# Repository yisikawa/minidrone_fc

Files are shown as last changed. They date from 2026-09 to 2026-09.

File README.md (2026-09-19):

# minidrone_fc — ミニドローン制御基板 KiCadプロジェクト

1S LiPo / 8520コアレスモーター×4 / 目標58g・上限70g

回路図は生成済みです。手で描く必要はありません。

---

## 1. 使い方

1. このフォルダごと `D:\KicadProjects\` などに置く（`D:\Kicad`
   の中には置かないでください。KiCad更新時に消える可能性があります）
2. `minidrone_fc.kicad_pro` をダブルクリック
3. 回路図（`.kicad_sch`）を開く

**KiCad 10で開くとファイル形式の変換確認が出ます。**
このプロジェクトはKiCad 7形式で生成されているためです。
「はい」で変換してください。以後は10形式で保存されます。

---

## 2. 最初にやること: XIAOのフットプリント設定

**U1のフットプリントは意図的に空欄にしてあります。**
XIAOはKiCad公式ライブラリに含まれず、環境によってライブラリ名が
変わるため、こちらで決め打ちできませんでした。

手順:

1. https://github.com/Seeed-Studio/OPL_Kicad_Library をZIPで取得
2. 展開し、`Seeed Studio XIAO Series Library/` 内の `.kicad_sym` を
   設定 → シンボルライブラリを管理 から追加
3. フットプリントは `.pretty` フォルダに入っていないと認識されません。
   単体の `.kicad_mod` ファイルの場合は `Seeed_XIAO.pretty` という
   フォルダを作って中に移動してから、
   設定 → フットプリントライブラリを管理 で追加
4. 回路図でU1を選択 → E キー → Footprintフィールドに
   `Seeed_XIAO:XIAO-ESP32C3-SMD` のような実際の名前を入力

U1のシンボル自体はこのプロジェクト内の `minidrone.kicad_sym` に
同梱してあるので、シンボルライブラリの導入は必須ではありません。
必要なのはフットプリントだけです。

---

## 3. 検証済みの内容

このプロジェクトは生成後、KiCadのエンジン（kicad-cli）で
以下を実機検証しています。

| 検証項目 | 結果 |
|---|---|
| 回路図ファイルの読み込み | 成功 |
| 基板ファイルの読み込み | 成功 |
| 部品点数 | 37点（設計意図と一致） |
| フットプリント割り当て | 全点一致（U1除く） |
| ネット数 | 22ネット |
| 接続点の総数 | 96点 |
| ネットリスト照合 | **全ネット完全一致** |
| 意図しない結線 | なし |
| 未結線ピン | 16点（すべてno_connect指定済み） |

つまり、書き出したネットリストが設計表と1本残らず一致することを
確認済みです。回路図の入力ミスはありません。

---

## 4. 設計資料からの変更点

基板化の過程で判明した誤りを訂正しています。

| 項目 | 変更前 | 変更後 | 理由 |
|---|---|---|---|
| 極性コンデンサ | `Device:CP` | `Device:C_Polarized` | CPはKiCad 5時代の名前。現行ライブラリに存在しない |
| フライバックダイオード | SS14 | **SS24** | SS14は1A定格。モーター電流1.62Aに対し余裕が乏しい。SS24は2A定格で、フットプリントは同じD_SMAなのでレイアウト変更不要 |
| C3〜C6の接続先 | Qのドレイン–ソース間 | **VBAT–GND間** | 高周波電流ループを閉じるのは電源側。低側スイッチではこちらが標準 |
| PTCヒューズ・電源SW | あり | **削除** | 6.5Aでは直列抵抗による電圧降下が推力損失に直結する |

---

## 5. ピン割り当て（ESP32-C3の制約を反映済み）

| XIAOピン | GPIO | ネット | 備考 |
|---|---|---|---|
| D0 | GPIO2 | 未使用 | ストラッピングピン。使用不可 |
| D1 | GPIO3 | BATT_SENSE | ADC1。Wi-Fi動作中も使える |
| D2 | GPIO4 | GATE_FL | |
| D3 | GPIO5 | GATE_FR | |
| D4 | GPIO6 | SDA | |
| D5 | GPIO7 | SCL | |
| D6 | GPIO21 | GATE_RL | |
| D7 | GPIO20 | IMU_INT | MPU6050のデータレディ割り込み |
| D8 | GPIO8 | 未使用 | ストラッピングピン |
| D9 | GPIO9 | 未使用 | BOOTピン |
| D10 | GPIO10 | GATE_RR | |

**A0はD0と同一ピンです。** そしてGPIO2はストラッピングピンなので、
電圧センスはD1（GPIO3）に置いてあります。またESP32-C3のADC2は
Wi-Fi動作中に使えないため、ADC1に属するピンでなければなりません。

D7をIMU割り込みに使っているので、将来UART受信機を追加する場合は
再割り当てが必要です。

---

## 6. 次の手順（基板レイアウト）

1. Eeschemaで ツール → フットプリントを割り当て を開き、U1だけ設定
2. 検査 → エレクトリカルルールチェック(ERC) を実行
3. ツール → 基板エディタで基板を更新
4. 基板の外形（Edge.Cuts）を35×35mmで描く
5. 配置は以下の順序で。**この順序が重要です**
   - モーターパッド J2〜J5 を四隅に
   - Q1〜Q4 と D1〜D4 を対応するパッドの直近（5mm以内）に
   - C3〜C6 を各Qの直近に
   - U1を中央、USB-Cが基板端から出る向きに
   - U2を裏面中央、モーター電流経路を避けた位置に
6. デザインルール: 最小クリアランス0.2mm、最小トレース幅0.25mm、
   ビア0.6mm/ドリル0.3mm
7. VBATとGNDはトレースではなく**ベタ（カッパープアー）**で。
   6.5Aには1oz銅で約4.0mm幅のトレースが必要で、35mm角では引けません
8. M_FL〜M_RRは1.0mm幅以上

### レイアウトで最も重要な点

**フライバックループの面積を最小化してください。**
モーターOFFの瞬間、逆起電力が モーター → D → VBAT → モーター を
流れます。このループが囲む面積がそのままノイズの放射源になり、
MPU6050の読み値を汚します。D1〜D4は必ずモーターパッドの真横に、
ビアを挟まずに配置してください。

---

## 7. 未検証事項

- **XIAOフットプリントの実寸**: Seeedのライブラリで裏面パッドや
  サーマルパッドの欠落が報告されています。実物を基板に当てて
  確認してください
- **MPU6050のQFN-24実装**: 手はんだは難度が高めです。困難なら
  GY-521完成基板（+1〜2g）に戻す判断もあり得ます
- **フレーム側の穴位置**: モーターパッドの座標はフレーム設計と
  同時に決める必要があります。基板レイアウトの前にフレーム寸法を
  確定させてください
- **ガーバー出力は未実施**: 発注前にDRCとガーバービューアでの
  目視確認を必ず行ってください

---

## 8. rev2 での修正（ERC結果を反映）

初版に対してERCを実行した結果、エラー3件・警告137件を修正しました。

| 症状 | 件数 | 原因 | 対応 |
|---|---|---|---|
| `power_pin_not_driven` | 3（エラー） | XIAOの3V3ピンを`power_in`と定義していた。実際はレギュレータ**出力**。またGND/VMCUに駆動源が明示されていなかった | 3V3を`power_out`に修正。VBAT/GND/VMCUにPWR_FLAGを追加 |
| `endpoint_off_grid` | 133（警告） | 部品座標が1.27mm（50mil）グリッドに乗っていなかった | 全部品を1.27mmグリッドにスナップ |
| `lib_symbol_mismatch` | 4（警告） | AO3400Aは本来`extends BSS138`の派生シンボル。展開して埋め込んだためライブラリ本体と差異が出る | 下記参照 |

### lib_symbol_mismatch について

これは**動作に影響しない表示上の警告**です。KiCad 7の回路図フォーマットが
`extends` を受け付けないため、生成側で展開する必要がありました。

解消したい場合は、KiCad 10で
**ツール → シンボルをライブラリから更新** を実行してください。
埋め込みコピーがKiCad 10のライブラリ版に置き換わり、警告が消えます。
接続には影響しません。

### 修正後の検証結果

- 回路図・基板ファイルの読み込み: 成功
- ネットリスト照合: **全22ネット・96接続点が完全一致**
- ワイヤ端点198点・ラベル99点・no_connect16点: **すべてグリッド上（off-grid 0）**
- BOM部品数: 37点（PWR_FLAG 3点はBOM除外）

---

## 9. rev2.1 での変更（2026-09-19）: 昇降圧DC-DC追加 + 4層化

### 9.1 なぜ必要だったか — 電源の設計欠陥

改訂前の電源経路は次のとおりでした。

```
VBAT (3.0-4.2V) --[D5 SS24, 約0.4V drop]--> VMCU --> U1(XIAO) pin14 "5V"
                        XIAO内蔵LDO --> +3V3 --> U2 GY-521, U3 BMP280
```

**この基板には昇圧素子が1つもありません。** そのため電池電圧が
「3.3V + LDOドロップアウト」を下回れば、3V3 レールは必ず追従して下がります。

8520コアレスモーター4個で 6.5A を引くと電池は 3.7V→3.4V 程度に沈み、
そこから D5 の 0.4V を引いて VMCU ≈ 3.0V、さらに XIAO 内蔵 LDO の
ドロップアウトを引くと **3V3 は 2.8〜2.95V**。
ESP32-C3 の動作下限 3.0V を公称電圧ですら下回っており、
**スロットルを上げた瞬間に MCU がリセットする**状態でした。

D5 が 0.4V を捨てていたのが最大の要因です。

### 9.2 対策 — TPS63002 昇降圧DC-DC の挿入

```
VBAT --> U4 TPS63002 (昇降圧, 5V固定) --> [D5 SS24] --> VMCU --> XIAO 5Vピン
             |                                              XIAO内蔵LDO --> +3V3（変更なし）
             +-- L1 2.2uH, C10 10uF(in), C11 22uF(out), C12 0.1uF(VINA)
```

- 電池が 3.0V まで落ちても出力5V固定。D5 で 0.4V 落ちても **4.6V** が XIAO に入る。
  内蔵LDO が 3.3V を作るのに必要なのは 3.5V 程度なので**余裕1V以上**
- 3.3V を XIAO の 3V3 ピンに逆流注入せず、XIAO が本来想定する "5V" ピンから
  入れているので、内蔵LDO と競合しない
- **+3V3 ネット（GY-521・BMP280）は一切変更していません**
- D5 は流用。向きも不変で、上流が VBAT から V5V に変わっただけ
- 効率は昇圧90%×LDO66%＝約60%だが、MCU消費0.33Wに対しモーターが24Wなので
  損失増は全体の0.75%

### 9.3 4層化

| 層 | 内容 |
|---|---|
| L1 F.Cu | 信号 + U1/U2 + 既存の VBAT ベタ4枚（そのまま残置） |
| **L2 In1.Cu** | **ベタGND 全面 2949mm²** |
| **L3 In2.Cu** | **VBAT プレーン 全面 2811mm²** |
| L4 B.Cu | 信号 + SMD部品 + GNDベタ |

改訂前は 6.5A を 0.6mm トレースで流していました。内層プレーン全面に変更。
GND スティッチングビアを 133本、衝突判定付きで自動配置しています。

### 9.4 U4 のローカルクリアランス 0.1mm について

VSON-10 は 0.5mm ピッチ・パッド幅 0.28mm でパッド間が 0.22mm しかなく、
VBAT が属する Power ネットクラスの 0.25mm 要求を物理的に満たせません。
Power の 0.25mm はモーター大電流の配線・ベタ向けポリシーであり、
ファインピッチ IC のピン間に適用する意図ではないため、
U4 のフットプリントにローカル上書きを設定しています。
JLCPCB の製造限界は 0.1mm なので 0.22mm は十分製造可能です。

### 9.5 検証結果

| 項目 | 改訂前 | 改訂後 |
|---|---|---|
| DRC エラー | 0 | **0** |
| DRC 警告 | 32 | 37（増分5はすべてシルク重なり） |
| 未配線アイテム | 4 | **1**（改善） |
| schematic_parity | 0 | **0**（回路図と基板が完全一致） |
| ERC | warning 5 / error 0 | warning 5 / error 0（同一） |
| 既存部品のパッド-ネット変更 | — | **D5 pad2 の VBAT→V5V のみ** |

検証は `kicad-cli pcb drc` / `kicad-cli sch erc` で実施しています。
**KiCad MCP の `run_drc` は未接続アイテムを検査しないため、
発注前の最終確認は必ず `kicad-cli` か GUI の DRC で行ってください。**

### 9.6 まだ残っている課題

- **未配線1件**: GND ベタの孤立島が1つ残っています（改訂前は4件）。
  電気的な害はありませんが、気になる場合は GUI で該当箇所を確認してください
- **シルク警告 29+3件**: 新規部品 C10/C11/C12 のリファレンス文字が
  隣接銅箔に重なります。この一角は部品とビアで埋まっており逃がす余地が
  ありませんでした。JLCPCB はパッド上のシルクを自動クリップします
- **Gerber / BOM / 実装座標は再出力していません。** 4層基板として
  出力し直す必要があります
- **実機でのブラウンアウト解消は未検証です**

### 9.7 改訂前の状態に戻すには

改訂前 (rev2) の状態は最初のコミットにそのまま記録してあります。
タグ `rev2` / `rev2.1` から参照できます。

```
git show rev2 --stat      改訂前の内容
git diff rev2 rev2.1      今回の改訂差分
```

git 導入前に使っていた手動チェックポイント (`*.before-gy521`, `*.before-4layer` など)
とローカルのフルバックアップは、履歴で代替できるため追跡対象外にしています
(`.gitignore` 参照)。

詳細な作業記録は `docs/superpowers/plans/2026-09-19-buckboost-and-4layer.md`。

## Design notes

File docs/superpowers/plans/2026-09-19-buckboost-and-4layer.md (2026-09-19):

# minidrone_fc rev2: 昇降圧DC-DC追加 + 4層化 実装計画

> **For agentic workers:** REQUIRED SUB-SKILL: superpowers:executing-plans または
> superpowers:subagent-driven-development で1タスクずつ実施すること。

**Goal:** 既存 rev2 基板のブラウンアウト欠陥を TPS63002 昇降圧DC-DC で解消し、
基板を2層から4層に変更して 6.5A の VBAT を内層プレーンで流せるようにする。

**Architecture:** 既存回路には手を入れず、VBAT と XIAO の "5V" ピンの間に
TPS63002（昇降圧・5V固定出力）を挿入する。既存の D5（SS24）は VBAT→VMCU の
直列位置から TPS63002出力→VMCU に移すだけで流用する。+3V3 ネット
（GY-521・BMP280）は XIAO 内蔵 LDO から供給されたまま一切変更しない。

**Tech Stack:** KiCad 10.0 / kicad MCP (swig backend)

**Spec:** このファイルの「背景」節に内包（既存プロジェクトの改修のため独立specなし）

## 背景: なぜ必要か

現状の電源経路:

```
VBAT (3.0-4.2V) --[D5 SS24, 約0.4V drop]--> VMCU --> U1(XIAO) pin14 "5V"
                                              +-- C2 100uF
                        XIAO内蔵LDO --> +3V3 (pin12) --> U2 GY-521, U3 BMP280
```

8520コアレスモーター4個で 6.5A を引くと電池は 3.7V→3.4V 程度に沈む。
そこから D5 の 0.4V を引いて VMCU ≈ 3.0V、さらに XIAO 内蔵 LDO の
ドロップアウトを引くと 3V3 レールは **2.8〜2.95V**。
ESP32-C3 の動作下限 3.0V を公称電圧ですら下回っており、
スロットルを上げた瞬間に MCU がリセットする。

この基板には昇圧素子が一切ないため、電池電圧が
「3.3V + LDOドロップアウト」を下回れば 3V3 は必ず追従して下がる。
LDO や配線の改善では原理的に解決できない。

## Global Constraints

- **既存の回路図ネットのうち、+3V3 / GND / GATE_* / G_* / M_* / SCL / SDA /
  BATT_SENSE は変更しないこと。** 変更してよいのは VBAT・VMCU の接続と
  新規追加分のみ。
- **git commit は行わない**（ユーザー指示）。チェックポイントは既存プロジェクトの
  慣習に従い `<file>.before-<変更名>` のファイルコピーで残す。
- 設計ルール: 最小クリアランス 0.2mm / 最小トレース幅 0.25mm / ビア 0.6mm・ドリル 0.3mm
- 基板外形は現状の 50 x 64mm を変更しない。取付穴 M2.2 x4（44x44mm ピッチ）も変更しない。
- 新規部品は KiCad 標準ライブラリのシンボル・フットプリントのみ使用する。

## 部品追加リスト

| Ref | Value | Symbol | Footprint | 接続 |
|---|---|---|---|---|
| U4 | TPS63002 | `Regulator_Switching:TPS63002` | `Package_SON:VSON-10-1EP_3x3mm_P0.5mm_EP1.65x2.4mm_ThermalVias` | 下記 |
| L1 | 2.2uH | `Device:L` | `Inductor_SMD:L_APV_ANR3015` | U4/L1(4) - U4/L2(2) |
| C10 | 10u | `Device:C` | `Capacitor_SMD:C_0805_2012Metric` | VBAT - GND（U4入力） |
| C11 | 22u | `Device:C` | `Capacitor_SMD:C_0805_2012Metric` | V5V - GND（U4出力） |
| C12 | 0.1u | `Device:C` | `Capacitor_SMD:C_0603_1608Metric` | VINA - GND |

TPS63002 のピン接続（データシート SLVS520C 実測確認済み）:

| ピン | 名称 | 接続 | 根拠 |
|---|---|---|---|
| 1 | VOUT | V5V | 出力 |
| 2 | L2 | L1 の片側 | インダクタ |
| 3 | PGND | GND | パワーグランド |
| 4 | L1 | L1 のもう片側 | インダクタ |
| 5 | VIN | VBAT | パワー段電源 |
| 6 | EN | VBAT | "1 enabled" → 常時イネーブル |
| 7 | PS/SYNC | VBAT | "1 disabled(power-save)" → 強制PWM。Wi-Fiバースト負荷の過渡応答重視 |
| 8 | VINA | VBAT（C12 でデカップリング） | 制御段電源 |
| 9 | GND | GND | ロジックグランド |
| 10 | FB | V5V | **固定出力版は FB を VOUT に接続**（データシート明記） |
| 11 | EPAD | GND | 露出パッドは PGND に接続 |

## ネット変更

| ネット | 変更前 | 変更後 |
|---|---|---|
| VBAT | ... , D5/2 | ... , D5/2 を削除。U4/5, U4/6, U4/7, U4/8, C10/1 を追加 |
| **V5V**（新規） | — | U4/1, U4/10, C11/1, D5/2 |
| VMCU | D5/1, C2/1, U1/14 | 変更なし |
| GND | ... | U4/3, U4/9, U4/11, C10/2, C11/2, C12/2 を追加 |

D5 の向きは変えない（pin2=カソード側が電源上流、pin1=アノード側が VMCU）。
上流が VBAT から V5V に変わるだけ。

---

### Task 1: 回路図に TPS63002 ブロックを追加し ERC を通す

**Files:**
- Modify: `minidrone_fc.kicad_sch`
- Checkpoint: `minidrone_fc.kicad_sch.before-buckboost`

- [x] **Step 1: チェックポイントを作成**

```bash
cp minidrone_fc.kicad_sch minidrone_fc.kicad_sch.before-buckboost
```

- [x] **Step 2: 変更前のネットリストを記録**

`list_schematic_nets` を実行し、19ネットであること、
VBAT が 17ピン、VMCU が 4ピンであることを記録する。

- [x] **Step 3: U4 / L1 / C10 / C11 / C12 を配置**

`batch_add_components` で上記「部品追加リスト」のシンボルを、
回路図の空き領域（既存部品と重ならない座標）に配置する。

- [x] **Step 4: 結線**

`batch_connect` で「ネット変更」表のとおり接続する。
D5/2 を VBAT から切り離して V5V に繋ぎ替えるのを忘れないこと。

**落とし穴（2026-09-19 に実際に踏んだ）:** この回路図はピンから短いスタブ配線を
伸ばし、その**反対端**にラベルを置く方式で描かれている。`batch_connect` の
`replace=true` はピン位置のラベルしか削除しないため、スタブ反対端の既存 `VBAT`
ラベルが残り、同じ配線上に `VBAT` と `V5V` が同居して**両ネットが短絡**した。

正しい手順:
1. `batch_connect` で V5V ラベルを置く
2. `delete_schematic_net_label` で **(90.17, 49.53) の `VBAT` ラベルを削除**する
3. V5V ラベルもスタブ反対端 (90.17, 49.53) に置き直し、既存の作図スタイルに揃える
   （ピン位置に置いたままだと「未接続の配線終端」警告が出る）
4. `list_schematic_nets` で V5V が **4ピンちょうど**であることを必ず確認する。
   16ピン以上になっていたら VBAT と短絡している

- [x] **Step 5: ネットリストを検証**

`list_schematic_nets` を実行。期待値（2026-09-19 実測で確認済み）:
- ネット数 19 → **22**（V5V・SW_L1・SW_L2 の3本が増える）
- VBAT: 17 → **22ピン**（D5/2 が抜け、U4/5・U4/6・U4/7・U4/8・C10/1・C12/1 が入る）
- V5V: **4ピン**（D5/2, U4/1, U4/10, C11/1）
- SW_L1: **2ピン**（U4/4, L1/1）／ SW_L2: **2ピン**（U4/2, L1/2）
- VMCU: **4ピン**（変更なし）
- +3V3: **7ピン**（変更なし）
- GND: 25 → **31ピン**

注: `list_schematic_nets` のピン数ヘッダは PWR_FLAG を含むが一覧には
表示されない。VBAT はヘッダ17に対し一覧16件、GND はヘッダ25に対し一覧24件
という差がある。そのため**絶対値ではなく上記の増減で判定すること。**

- [x] **Step 6: ERC を実行**

`run_erc` を実行。期待値: **エラー0件**。
`power_pin_not_driven` が出た場合、V5V に PWR_FLAG を追加する
（既存プロジェクトが VBAT/GND/VMCU で同じ対処をしている）。

---

### Task 2: 基板を4層に変更する

**Files:**
- Modify: `minidrone_fc.kicad_pcb`
- Checkpoint: `minidrone_fc.kicad_pcb.before-4layer`

- [x] **Step 1: チェックポイントを作成**

```bash
cp minidrone_fc.kicad_pcb minidrone_fc.kicad_pcb.before-4layer
```

- [x] **Step 2: 層を追加**

`add_layer` で `In1.Cu` と `In2.Cu` を signal/power 層として追加し、
`get_layer_list` で F.Cu / In1.Cu / In2.Cu / B.Cu の4層になったことを確認する。

- [x] **Step 3: F.Cu の VBAT ベタは削除しない（方針変更）**

当初は F.Cu の VBAT ベタ4枚を削除する計画だったが、**削除しないことにした。**

理由:
1. **ゾーンを削除する専用 MCP ツールが存在しない**（`delete_graphic` は
   グラフィック用でゾーンには使えない）
2. 残しても VBAT の銅箔が増えるだけで害がない。F.Cu の配線余地は
   既に配線完了済みのため不要
3. 危険な操作を1つ減らせる

目的（L2 ベタGND・L3 VBAT プレーンの獲得）は追加のみで達成できる。

- [x] **Step 4: 内層ベタを追加**

`add_copper_pour` で以下を作成する。`outline` を省略すると基板外形が使われる。

- `In1.Cu` = **GND**、clearance 0.2
- `In2.Cu` = **VBAT**、clearance 0.2

- [x] **Step 5: ゾーンを再充填して検証**

**注意: `refill_zones` は swig バックエンドで segfault の既知リスクあり。**
実行直前に `cp minidrone_fc.kicad_pcb minidrone_fc.kicad_pcb.before-refill` で
チェックポイントを取ること。（2026-09-19 の実行では segfault は発生しなかった）

**既知の誤検知:** `refill_zones` が
「Auto-save refused: ... changed externally」と警告を返すことがあるが、
これは MCP 側の mtime 記録が自身の直前の書き込みで古くなったための誤検知で、
**実際にはディスクに書き込まれている**。ファイルサイズの増加と
`grep -c filled_polygon` で確認し、`reload_board` で MCP を再同期すること。

検証結果（2026-09-19 実測）: 全7ゾーン `isFilled: true`。
In1.Cu GND = 2956mm²、In2.Cu VBAT = 2949mm²（基板面積 3200mm² のほぼ全面）。

---

### Task 3: 新規部品を配置し配線する

**Files:**
- Modify: `minidrone_fc.kicad_pcb`
- Checkpoint: `minidrone_fc.kicad_pcb.before-dcdc-place`

- [x] **Step 1: チェックポイントを作成**

```bash
cp minidrone_fc.kicad_pcb minidrone_fc.kicad_pcb.before-dcdc-place
```

- [x] **Step 2: 回路図の変更を基板に反映**

`sync_schematic_to_board` を実行し、U4 / L1 / C10 / C11 / C12 が
基板に追加されたことを `get_component_list` で確認する。

- [x] **Step 3: U4 ブロックを配置**

B.Cu（他のSMD部品と同じ面）の空き領域に配置する。
現状 y=50〜64 の帯（J1 BATT・C1・C2 のあるエリア）に空きがあるため、
**C2（VMCU のバルク、座標 34,56）と J1（BATT、座標 8,54）の間**に U4 を置く。
これにより VBAT 入口（J1）→ U4 → C2/VMCU が最短で繋がる。

配置後 `check_placement_clearance` で既存部品と干渉しないことを確認する。

**レイアウト上の必須要件:**
- L1 は U4 の L1/L2 ピンの直近（3mm以内）に置く。スイッチングノードの
  ループ面積がそのままEMIになる
- C10（入力）は U4 の VIN/PGND ピンの直近に置く
- C11（出力）は U4 の VOUT/PGND ピンの直近に置く
- U4 の露出パッド直下にサーマルビアを配置し In1.Cu(GND) に落とす

- [x] **Step 4: 配線**

`route_pad_to_pad` で V5V / VBAT / GND / スイッチングノードを接続する。
V5V と VBAT は **0.5mm 幅以上**（MCU電流のみなので大電流は不要だが、
インピーダンスを下げる）。

- [x] **Step 5: ゾーン再充填**

`refill_zones` を実行する。

---

### Task 4: DRC を通し、警告を仕上げる

**Files:**
- Modify: `minidrone_fc.kicad_pcb`

- [x] **Step 1: DRC を実行**

`run_drc` を実行し、違反を種別ごとに記録する。

- [x] **Step 2: エラーをゼロにする**

`error` severity の違反をすべて解消する。
クリアランス違反は部品をずらすか配線を引き直す。

- [x] **Step 3: silk_over_copper 警告を減らす**

変更前は 26件あった。`move_footprint_text` でシルクを
銅箔・パッドから逃がす。JLCPCB はパッド上のシルクをクリップするため、
リファレンス指示子が読めなくなるのを防ぐ目的。

- [x] **Step 4: 最終検証**

以下をすべて満たすことを確認して完了とする。

- `run_erc`: エラー0件
- `run_drc`: **エラー0件**
- `query_zones`: 全ゾーン `isFilled: true`
- `get_layer_list`: F.Cu / In1.Cu / In2.Cu / B.Cu の4層
- `list_schematic_nets`: 20ネット、V5V が4ピン、+3V3 が7ピン

## 完了後に残る課題（この計画の対象外）

- Gerber / BOM / 実装座標の再出力（成果物範囲外）
- 4層化に伴う JLCPCB の製造コスト変更の確認
- 実機でのブラウンアウト解消の検証

---

## 実施結果（2026-09-19 完了）

### 最終検証値

| 項目 | 変更前 | 変更後 | 判定 |
|---|---|---|---|
| DRC 違反 | 32（すべて warning） | 37（すべて warning） | エラー0を維持。増分5はすべてシルク |
| DRC エラー | 0 | **0** | OK |
| 未配線アイテム | 4 | **1** | 改善 |
| schematic_parity | 0 | **0** | 回路図と基板が完全一致 |
| ERC | warning 5 / error 0 | warning 5 / error 0 | 変更前と同一 |
| 既存部品のパッド-ネット変更 | — | **D5 pad2 の VBAT→V5V のみ** | 意図どおり |

増分5件のシルク警告は silk_over_copper 26→29、silk_overlap 1→3。
新規部品 C10/C11/C12 のリファレンス文字が隣接銅箔に重なるもので、
この一角は J1・D5・C1・U4・L1 とスティッチングビアで埋まっており逃がす余地がない。
ベースラインに既に26件ある同種の警告であり、エラーではなく、
JLCPCB はパッド上のシルクを自動クリップするため許容とした。

### 実際に行った変更

1. 回路図に U4(TPS63002) / L1(2.2uH) / C10(10u) / C11(22u) / C12(0.1u) を追加
2. D5 の上流を VBAT から V5V に変更（D5 の向きは不変）
3. In1.Cu(GND) / In2.Cu(VBAT) の内層プレーンを追加し4層化
4. U4 にローカルクリアランス 0.1mm を設定（下記参照）
5. GND スティッチングビア 133本を自動配置（衝突判定付き）
6. GND ゾーンの島除去モードを ALWAYS に設定

### U4 のローカルクリアランス 0.1mm について

VSON-10 は 0.5mm ピッチ・パッド幅 0.28mm でパッド間が 0.22mm しかなく、
VBAT が属する Power ネットクラスの 0.25mm 要求を物理的に満たせない。
Power の 0.25mm はモーター大電流の配線・ベタ向けポリシーであり、
ファインピッチ IC のピン間に適用する意図のものではないため、
U4 のフットプリントにローカル上書きを設定した。
JLCPCB の製造限界は 0.1mm なので 0.22mm は十分製造可能。

### 作業中に検出・修正した不具合

| 不具合 | 原因 | 検出方法 |
|---|---|---|
| VBAT と V5V の短絡 | `batch_connect` の `replace` がスタブ反対端の既存ラベルを消さない | ネットリスト検証（V5V が 4→20ピン） |
| VBAT と V5V の短絡（基板側） | 既存 VBAT トレースが D5/2 を中継点に使用していた | DRC shorting_items |
| V5V が C11 の GND パッドを貫通 | C11 の V5V パッドが進入方向と逆側 | DRC shorting_items |
| **U1 pad7 に GATE_RL 重複、U2 pad8(GY-521 INT) に +3V3 直結** | `sync_schematic_to_board` が回路図にない割り当てを追加 | 変更前後のパッド-ネット差分 |

最後の1件は DRC でも ERC でも検出されない。
**`sync_schematic_to_board` の後は必ず変更前後のパッド-ネット差分を取ること。**

### ツール上の注意点（次回のために）

- **`mcp__kicad__run_drc` は未接続アイテムを検査しない。** エラー0でも配線が
  繋がっていない場合がある。`kicad-cli pcb drc` を正とすること
- **`mcp__kicad__refill_zones` は4層フルプレーンで30秒タイムアウトする。**
  KiCad 同梱の `pcbnew` Python（`D:\KiCad\10.0\bin\python.exe`）で
  `ZONE_FILLER(b).Fill(b.Zones())` を直接実行して回避した
- `refill_zones` / `sync_schematic_to_board` の後は MCP の mtime 記録が古くなり
  以降の書き込みが「Auto-save refused」で無視される。**必ず `reload_board` すること**
- pcbnew Python の落とし穴:
  - `b.Tracks()` / `b.Zones()` は**一度しかイテレートできない**。`list()` で取り置く
  - ゾーンは `b.GetArea(i)` で取ると正しい `ZONE` 型になる
  - `b.Remove()` を呼ぶと**以降の既存ラッパが無効化される**。
    読み取りを全部終えてから変更すること
  - `PCB_VIA.GetWidth()` は KiCad 10 で層引数が必須

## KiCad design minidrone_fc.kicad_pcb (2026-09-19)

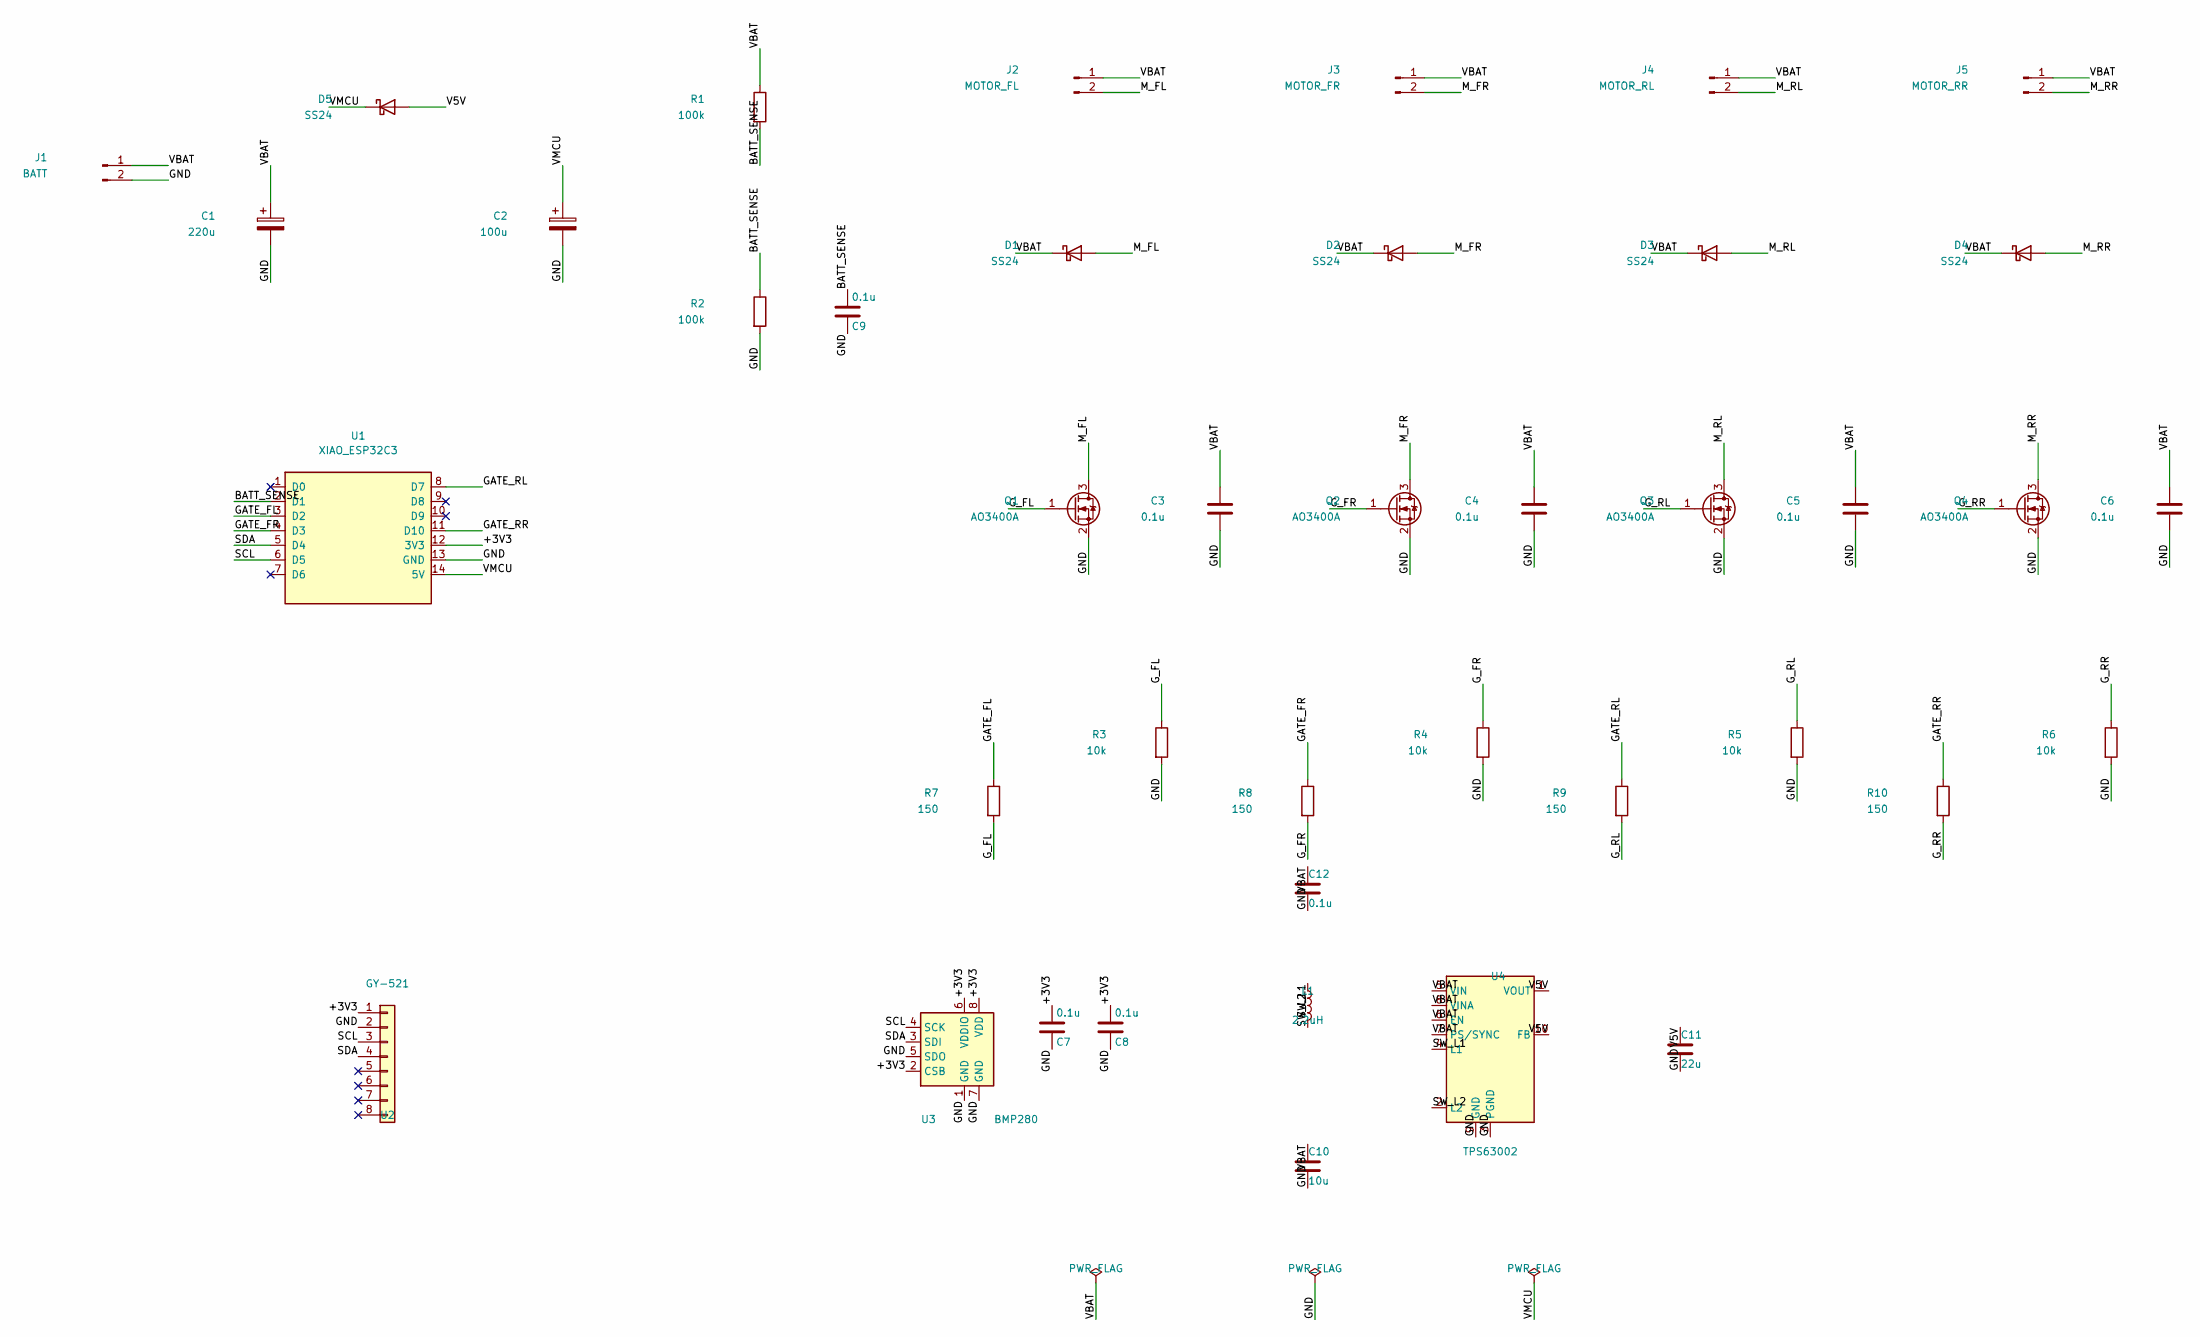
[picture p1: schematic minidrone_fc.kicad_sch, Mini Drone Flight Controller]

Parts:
C1: 220u; CP_Elec_6.3x5.3; Voltage 10V; MPN CS1A221M-CRE54; LCSC C116413
C2: 100u; CP_Elec_6.3x5.3; Voltage 16V; MPN CK1C101M-CRE54; LCSC C129250
C3, C4, C5, C6, C7, C8, C9: 0.1u; C_0603_1608Metric; MPN CC0603KRX7R9BB104; LCSC C14663
C10: 10u; C_0805_2012Metric
C11: 22u; C_0805_2012Metric
C12: 0.1u; C_0603_1608Metric
D1, D2, D3, D4, D5: SS24; D_SMA; MPN SS24; LCSC C115726
J1: BATT; JST_PH_S2B-PH-K_1x02_P2.00mm_Horizontal; MPN S2B-PH-K-S(LF)(SN); LCSC C173752
J2: MOTOR_FL; TestPoint_2Pads_Pitch2.54mm_Drill0.8mm
J3: MOTOR_FR; TestPoint_2Pads_Pitch2.54mm_Drill0.8mm
J4: MOTOR_RL; TestPoint_2Pads_Pitch2.54mm_Drill0.8mm
J5: MOTOR_RR; TestPoint_2Pads_Pitch2.54mm_Drill0.8mm
L1: 2.2uH; L_APV_ANR3015
Q1, Q2, Q3, Q4: AO3400A; SOT-23; MPN AO3400A; LCSC C20917
R1, R2: 100k; R_0603_1608Metric; MPN 0603WAF1003T5E; LCSC C25803
R3, R4, R5, R6: 10k; R_0603_1608Metric; MPN RK73H1JTTD1002F; LCSC C130232
R7, R8, R9, R10: 150; R_0603_1608Metric; MPN 0603WAF1500T5E; LCSC C22808
U1: XIAO_ESP32C3; XIAO-ESP32-C3-DIP
U2: GY-521; PinHeader_1x08_P2.54mm_Vertical
U3: BMP280; Bosch_LGA-8_2x2.5mm_P0.65mm_ClockwisePinNumbering; MPN WF282A; LCSC C22388663
U4: TPS63002; VSON-10-1EP_3x3mm_P0.5mm_EP1.65x2.4mm_ThermalVias

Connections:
+3V3: C7.1, C8.1, U1.12 (3V3), U2.1, U3.2 (CSB), U3.6 (VDDIO), U3.8 (VDD)
BATT_SENSE: C9.1, R1.2, R2.1, U1.2 (D1)
GATE_FL: R7.1, U1.3 (D2)
GATE_FR: R8.1, U1.4 (D3)
GATE_RL: R9.1, U1.8 (D7)
GATE_RR: R10.1, U1.11 (D10)
GND: C1.2, C2.2, C3.2, C4.2, C5.2, C6.2, C7.2, C8.2, C9.2, C10.2, C11.2, C12.2, J1.2, Q1.2 (S), Q2.2 (S), Q3.2 (S), Q4.2 (S), R2.2, R3.2, R4.2, R5.2, R6.2, U1.13 (GND), U2.2, U3.1 (GND), U3.5 (SDO), U3.7 (GND), U4.3 (PGND), U4.9 (GND), U4.11 (PGND)
G_FL: Q1.1 (G), R3.1, R7.2
G_FR: Q2.1 (G), R4.1, R8.2
G_RL: Q3.1 (G), R5.1, R9.2
G_RR: Q4.1 (G), R6.1, R10.2
M_FL: D1.2 (A), J2.2, Q1.3 (D)
M_FR: D2.2 (A), J3.2, Q2.3 (D)
M_RL: D3.2 (A), J4.2, Q3.3 (D)
M_RR: D4.2 (A), J5.2, Q4.3 (D)
SCL: U1.6 (D5), U2.3, U3.4 (SCK)
SDA: U1.5 (D4), U2.4, U3.3 (SDI)
SW_L1: L1.1, U4.4 (L1)
SW_L2: L1.2, U4.2 (L2)
V5V: C11.1, D5.2 (A), U4.1 (VOUT), U4.10 (FB)
VBAT: C1.1, C3.1, C4.1, C5.1, C6.1, C10.1, C12.1, D1.1 (K), D2.1 (K), D3.1 (K), D4.1 (K), J1.1, J2.1, J3.1, J4.1, J5.1, R1.1, U4.5 (VIN), U4.6 (EN), U4.7 (PS/SYNC), U4.8 (VINA)
VMCU: C2.1, D5.1 (K), U1.14 (5V)

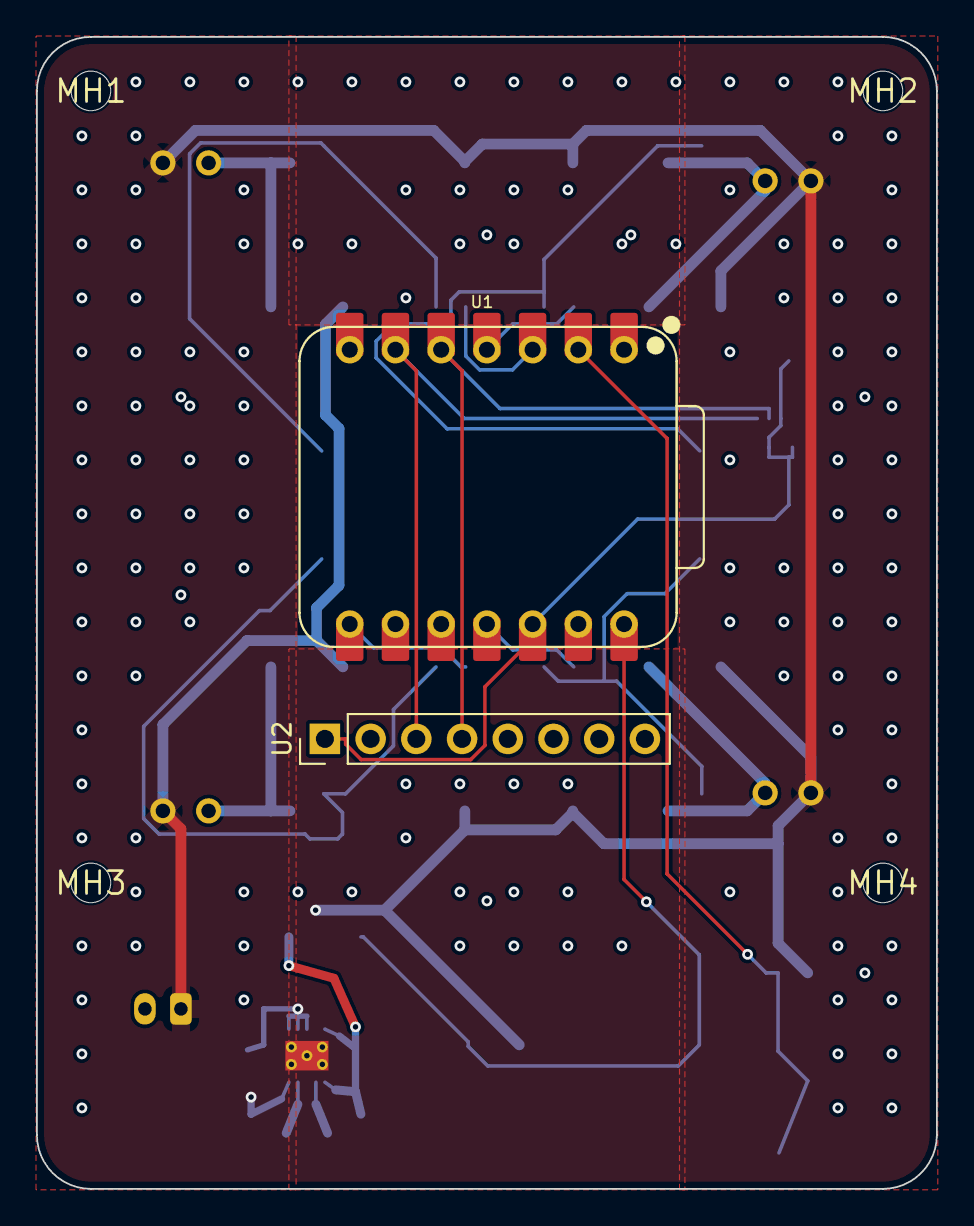
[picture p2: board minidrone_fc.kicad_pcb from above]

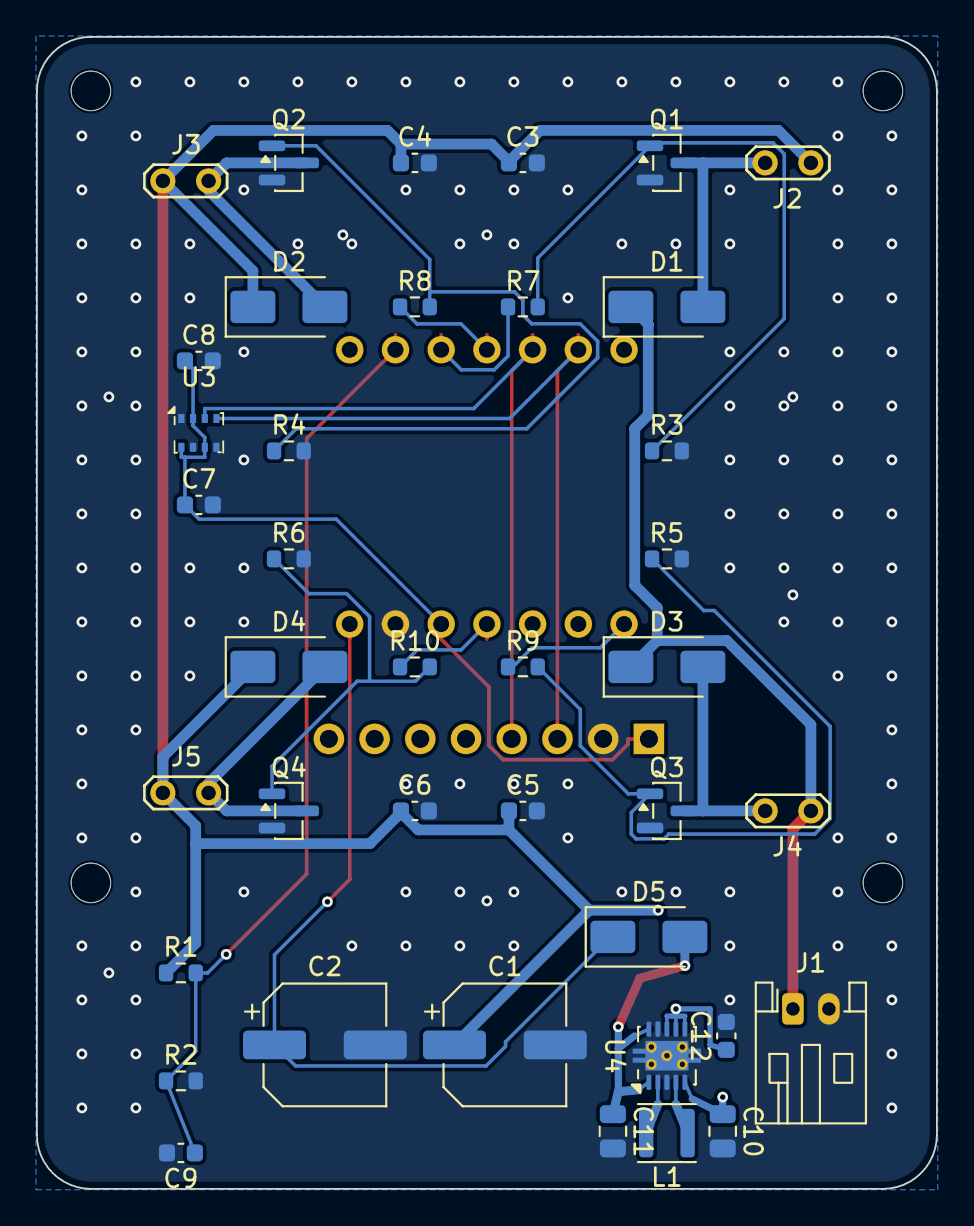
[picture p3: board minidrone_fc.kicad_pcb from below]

Board: 4 copper layers, 50.0 x 64.0 mm, 45 parts (39 on the bottom side), 22 nets.

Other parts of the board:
MH1, MH2, MH3, MH4: MountingHole_2.2mm

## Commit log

2026-09-19 rev2: 昇降圧DC-DC追加前の状態
    2026-08-23 から 2026-08-29 にかけて作り込まれた rev2 の状態をそのまま記録する。
    git 導入前に手動の .before-* コピーで管理されていたものを、ここから履歴に移行する。
    構成: XIAO ESP32C3 + GY-521(MPU-6050) + BMP280 + AO3400A x4 + SS24 x4
    1S LiPo / 8520 コアレスモーター x4 / 2層 50x64mm
    検証値 (kicad-cli):
    DRC 違反 32 (すべて warning) / エラー 0 / 未配線 4
    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
    [minidrone_fc.kicad_pcb, minidrone_fc.kicad_sch]
2026-09-19 rev2.1: 昇降圧DC-DC(TPS63002)を追加し4層化
    ## なぜ
    改訂前の基板には昇圧素子が1つもなく、電池電圧が「3.3V + LDOドロップアウト」
    を下回れば 3V3 レールは必ず追従して下がる構造だった。
    8520コアレスモーター4個で 6.5A を引くと電池は 3.7V→3.4V に沈み、
    そこから D5(SS24) の 0.4V を引いて VMCU ≈ 3.0V、
    さらに XIAO 内蔵 LDO のドロップアウトを引くと 3V3 は 2.8〜2.95V。
    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
    [minidrone_fc.kicad_pcb, minidrone_fc.kicad_sch]
2026-09-19 docs: 計画書に混入した制御文字を除去
    Python 文字列で `D:\KiCad\10.0\bin\python.exe` の `\10` が8進エスケープ
    (0x08 = backspace)、`\b` がバックスペースとして解釈され、
    ファイルに制御文字が2個書き込まれていた。
2026-09-19 docs: README のバックアップ節を git 履歴ベースに書き換え
    公開リポジトリではローカルの絶対パスを参照しても意味がないため、
    改訂前の状態の参照方法をタグ rev2 / rev2.1 ベースに変更。
2026-09-19 bom: 新規部品4点に LCSC 品番を追加
    4層での製造データ再出力にあたり、rev2.1 で追加した部品に
    JLCPCB の品番が未設定で BOM が不完全だったため設定。
    U4 TPS63002DRCR C116655 VSON-10-EP(3x3) 在庫1153
    L1 NRS3015T2R2MNGHV C1329483 2.2uH/1.5A/3x3mm AEC-Q200 在庫506
    C10 10uF 25V X5R 0805 C15850 Basic part (実装無料) 在庫350万
    C11 22uF 16V X5R 0805 C128856 在庫20058
    C12 0.1uF 0603 C14663 C3-C9 と同一品
    プロパティ追加のみで結線は不変。
    ネットリスト 22ネット / V5V 4ピン / +3V3 7ピン で変更前と一致、
    ERC も warning 5 / error 0 で同一であることを確認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
    [minidrone_fc.kicad_sch]
